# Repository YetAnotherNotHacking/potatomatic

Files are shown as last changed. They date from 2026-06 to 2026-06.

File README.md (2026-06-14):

<p align="center">
  potatomatic-cover
</p>

# Potatomatic turret system
Potatomatic started as a project to move a 5.5lb potato cannon reliably on a robotic turret mechanism, and to have intelligent tracking allowing it to automatically control itself for a majority of it's operation. We then realized that its super simple to make it adaptable to anything! So in the end, this project is a robust 2 axis gimbal with a mounting solution allowing anything to be mounted easily for use in the future.

## Assembly guide
A complete guide to printing, assembly, wiring and programming can be found [here](https://docs.google.com/presentation/d/1axM6zSbhQgakMfhfwyYygMVe3PKqu1EDHwFVl_Ch5AA/edit?usp=sharing).

## Bom:
See the BOM.csv for the BOM. It includes everything you would need to build it assuming you had only filament. See the google doc below for what the HackClub funding would be spent on, as thats the materials I still need.

**If you dont have anything, use the BOM.csv**

**I will be purchasing from the google doc BOM, as it omits things I already have**

All of the sourcing and stuff was done on this google doc:
[Google Doc BOM](https://docs.google.com/document/d/13_K_9BwoxUnn-ND7bYpN881mAYJAPF880q18yzIybXw/edit?usp=sharing)
See the "sourcing" tab for the real BOM. The first page is a general list without prices or source locations. Note that prices are calculated for Utah.

## Project Cost Breakdown
**For HackClub reviewer: I will NOT be purchasing filament with the project grant. I have already printed all of the components out with my own funds using my PETG.**

### Summary

| Category | With Filament | Without Filament |
|---|---|---|
| Total (inlc-tax) | $158.38 | $116.54 |
| Amazon Section | $123.16 (~$132.34 w/ tax) | $84.22 (~$90.50 w/ tax) |
| Bolt Depot Section | $26.04 | $26.04 |

---

## Amazon Parts

| Item | Cost |
|---|---|
| Filament | $38.94 |
| Controller (Arduino + stepper driver combo) | $17.83 |
| Stepper output flanges | $6.99 |
| DC-DC Step Down (24V → 12V) | $9.99 |
| Barrel Power Connector | $3.97 |
| Motor Cabling | $7.89 |
| C13 Socket | $5.99 |
| Thrust Bearings (2× 15×28×2mm) | $12.38 |
| Thrust Bearing (1× 80×105×4mm) | $9.19 |
| M3 Screw Set | $9.99 |

---

## Bolt Depot Parts

| Item | Cost |
|---|---|
| 4× 1.5" 7/16 Bolts | $2.72 |
| 9× 1.25" 7/16 Bolts | $5.31 |
| 13× 7/16 Nuts | $4.94 |

## 3D model
{4FDD96C2-EDEC-4343-98A4-A21E9CE5DD90}

## Wiring
Below is very professional Google Slides diagram of the wiring. I omitted the pi to better fit on one slide, since its only USB connectors that can go in one place one way. Note my typo, apparently cat5a doesnt exist. I meant cat5e. I got mixed up with cat6a which I use for my homelab.

wiring

The pi will have a webcam conencted, and serial connected to the control board. The wiring for this project is very simple, there is a limited number of electrical components other than the motors and camera and control boards. The control board does almost everything, if you look at what I linked its a steal honestly.

## Other notes:
The plan is to have entirely custom firmware for the turret, it will use a pi 5 that I already have as well as a camera attached to the turret (will have to be built before I can get a good idea of the best place) for targetting automatically. The main control will use the linked arduino stepper controller board with the pi talking to it with serial commands. There is a later intention of mounting it ontop of my friends car for some funny turret activities (dont ask) as well as adapting it for directional antennas to do radio astronomy, connecting to gpredict.

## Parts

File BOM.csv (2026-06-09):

name | number | link | cost | total
Controller, Arduino, Stepper Driver combo | 1 | https://www.amazon.com/Printer-Engraving-Expansion-Controller-Arduino/dp/B074DVRZDL/137-9649963-2915629 | 17.83 | 17.83
Stepper output flanges | 1 | https://www.amazon.com/ZXHAO-Flange-Coupling-Motors-Bearing/dp/B07HK8LQWC/ | 6.99 | 6.99
DCDC Stepdown 24v-12v | 1 | https://www.amazon.com/EPBOWPT-Converter-Regulator-Voltage-Transformer/dp/B07V6X6L89 | 9.99 | 9.99
Barrel power connector | 1 | https://www.amazon.com/California-JOS-Male-Female-2-1x5-5mm/dp/B0CR8TZ41W | 3.97 | 3.97
JST-XH terminated cabling | 1 | https://www.amazon.com/ACEIRMC-10Pairs-Connector-Connectors-Compatible/dp/B0D3LV6X3Y | 7.89 | 7.89
C13 Male Connectors | 1 | https://www.amazon.com/Panel-Adapter-Connector-Socket-MXR/dp/B07DCXKNXQ | 5.99 | 5.99
Thrust Bearings 15x28x2mm | 2 | https://www.amazon.com/uxcell-AXK5578-Bearings-Diameter-Thickness/dp/B07GC9J18L?xpid=99cDBU9-PCR3I | 6.19 | 12.38
Thrust Bearings 80x105x4mm | 1 | https://www.amazon.com/uxcell-AXK5578-Bearings-Diameter-Thickness/dp/B07GC94P6Y?xpid=99cDBU9-PCR3I | 9.99 | 9.99
M3 Fastener set | 1 | https://www.amazon.com/Fgruh-750PCS-Assortment-Washers-Assorted/dp/B0FGV5FCBN?th=1 | 9.99 | 9.99
7/16-14 1 1/2" Bolts | 4 | https://boltdepot.com/Product-Details?product=377 | 0.68 | 2.72
7/16-14 1 1/4" Bolts | 9 | https://boltdepot.com/Product-Details?product=376 | 0.59 | 5.31
7/16-14 Nuts | 13 | https://boltdepot.com/Product-Details?product=5574 | 0.38 | 4.94
CR20 Pro power supply | 1 | https://store.creality.com/products/creality-350w-power-supply | 22.81 | 22.81
Creality 42-40 Nema 17 Stepper | 1 | https://www.creality3dofficial.com/en/products/2pcs-ce-certification-2phase-reprap-stepper-motor-42-motor-42-40-3d-printer | 10.495 | 10.495
Creality 42-34 Nema 17 Stepper | 2 | https://www.creality3dofficial.com/en/products/2pcs-ce-certification-2phase-reprap-stepper-motor-42-motor-42-40-3d-printer | 10.495 | 20.99
Cat5 Ethernet cable | 1 | https://www.amazon.com/Monoprice-Flexboot-Cat5e-Ethernet-Patch/dp/B00KXM1LZ8?s=pc&th=1 | 2.42 | 2.42
6mm gt2 timing belt | 1 | https://www.amazon.com/Timing-Meters-Creality-Anycubic-Printer/dp/B097T3Y6WW?s=industrial&th=1 | 9.99 | 9.99
Power cabling | 1 | https://www.amazon.com/Voltage-Automotive-Primary-Security-Electrical/dp/B0CZ73SQP8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 | 8.99 | 8.99

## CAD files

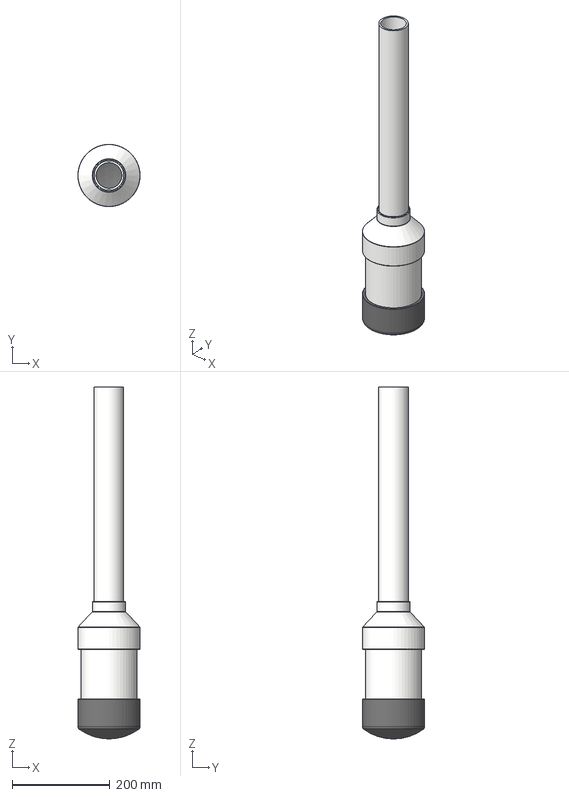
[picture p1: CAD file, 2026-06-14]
cad/cannon/cannonassemblyv2.step
127.0 x 127.0 x 719.2 mm

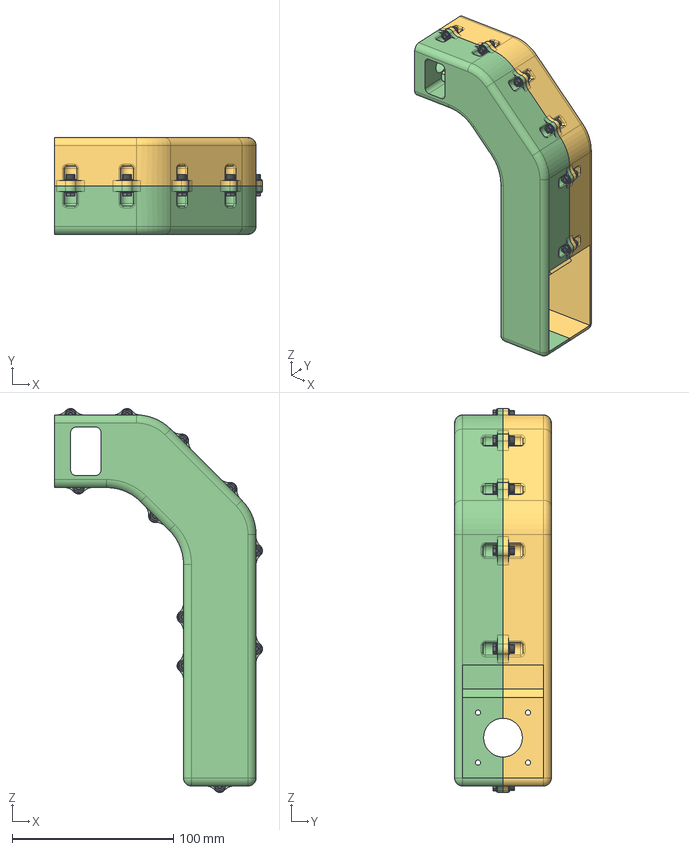
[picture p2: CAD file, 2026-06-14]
cad/assemblies/assem_manu1_armelementv1.step
129.0 x 60.0 x 238.0 mm

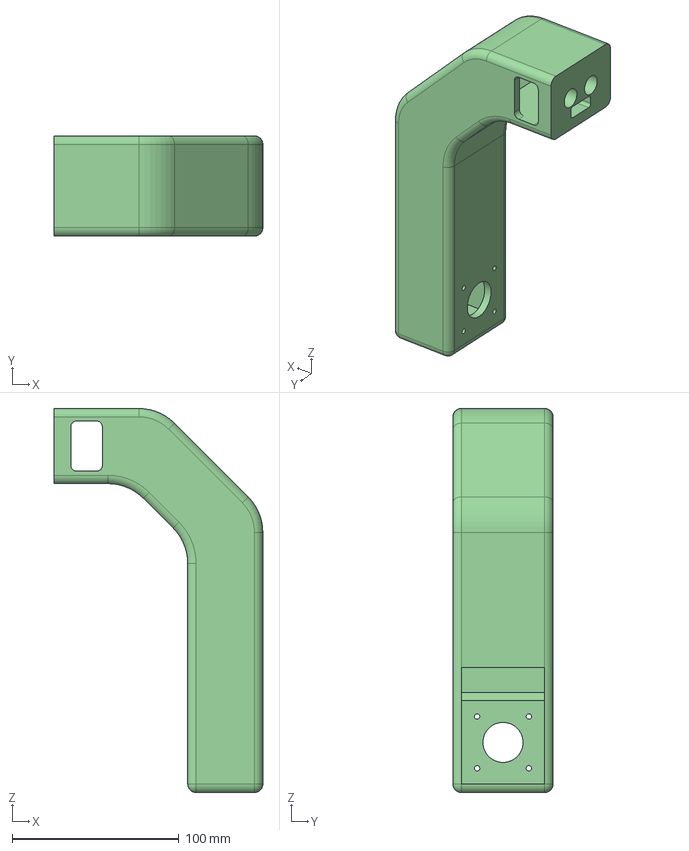
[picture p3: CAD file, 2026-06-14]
cad/geometry/armelementv1.step
125.0 x 60.0 x 230.0 mm

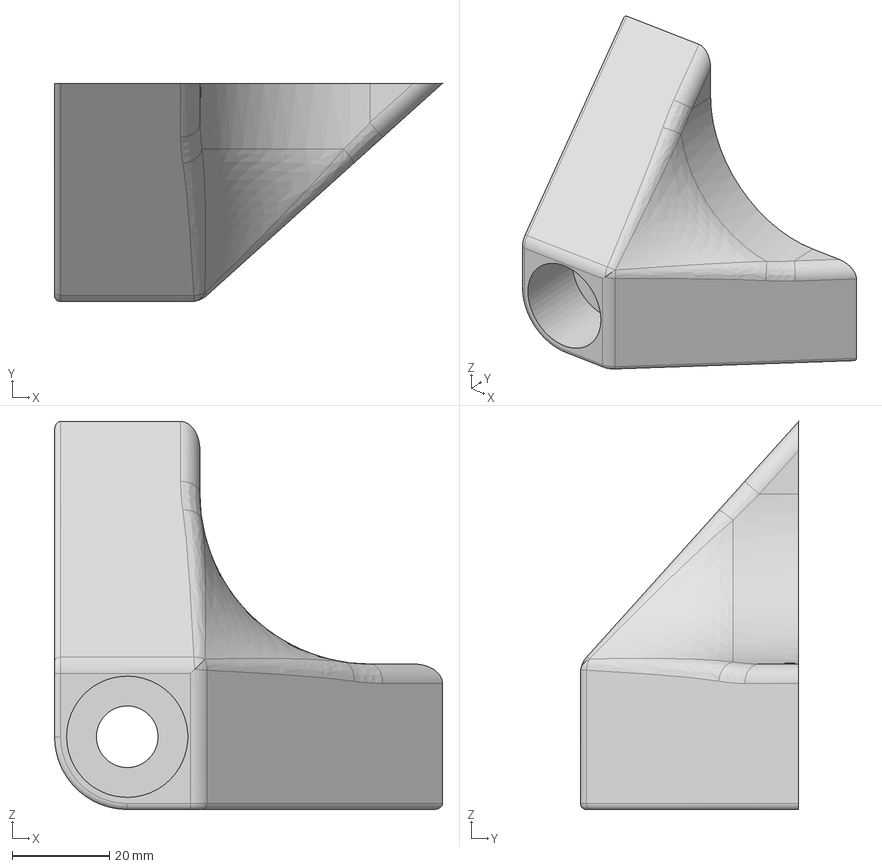
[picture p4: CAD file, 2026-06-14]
cad/manufacturable/basefootv1.step
80.0 x 45.0 x 80.0 mm

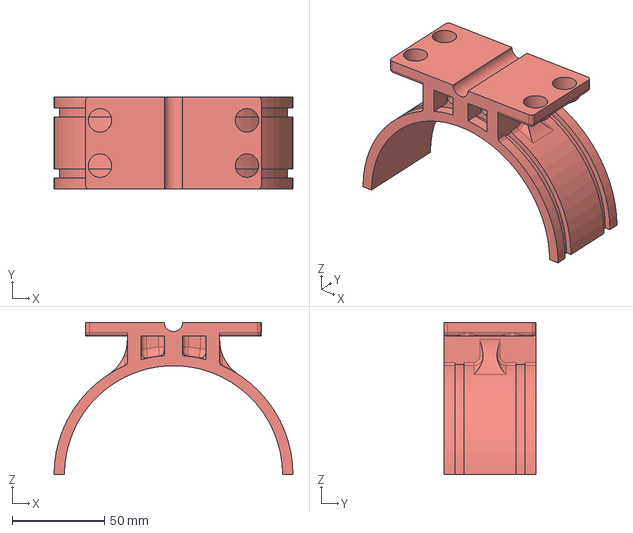
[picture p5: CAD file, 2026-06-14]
cad/payload_adapters/cradle_cannon.step
129.3 x 50.0 x 82.5 mm

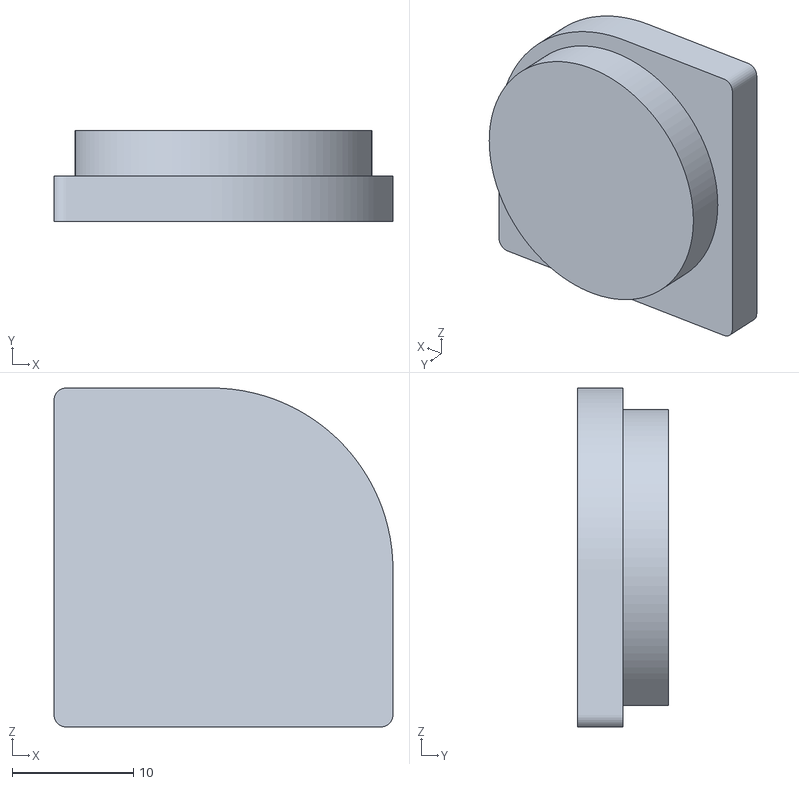
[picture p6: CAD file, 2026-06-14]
manufacturables/footcapv1.stl
28.0 x 7.50 x 28.0

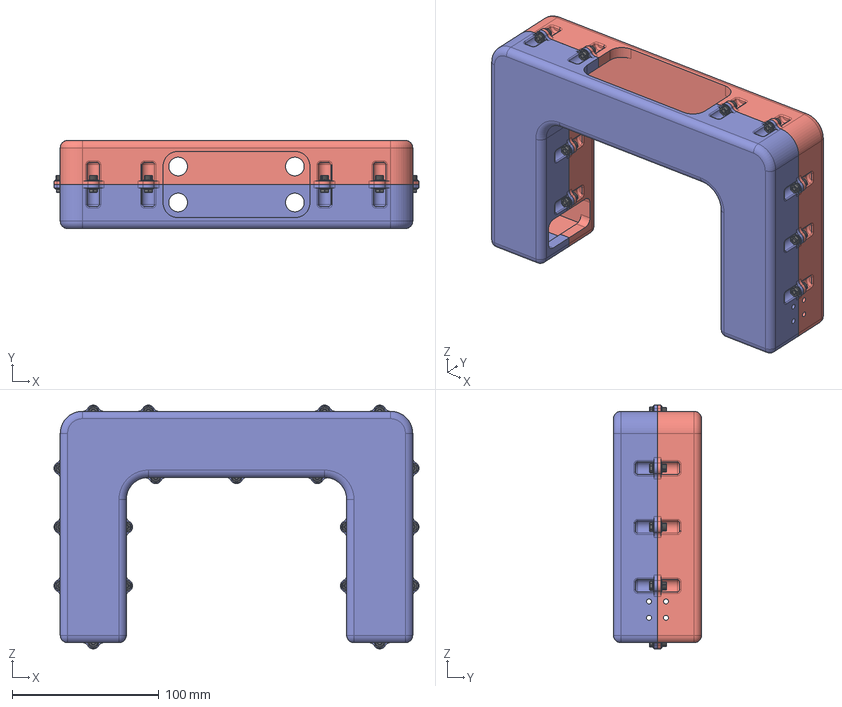
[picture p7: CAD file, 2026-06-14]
cad/assemblies/assem_wristelement2.step
248.5 x 60.0 x 166.0 mm

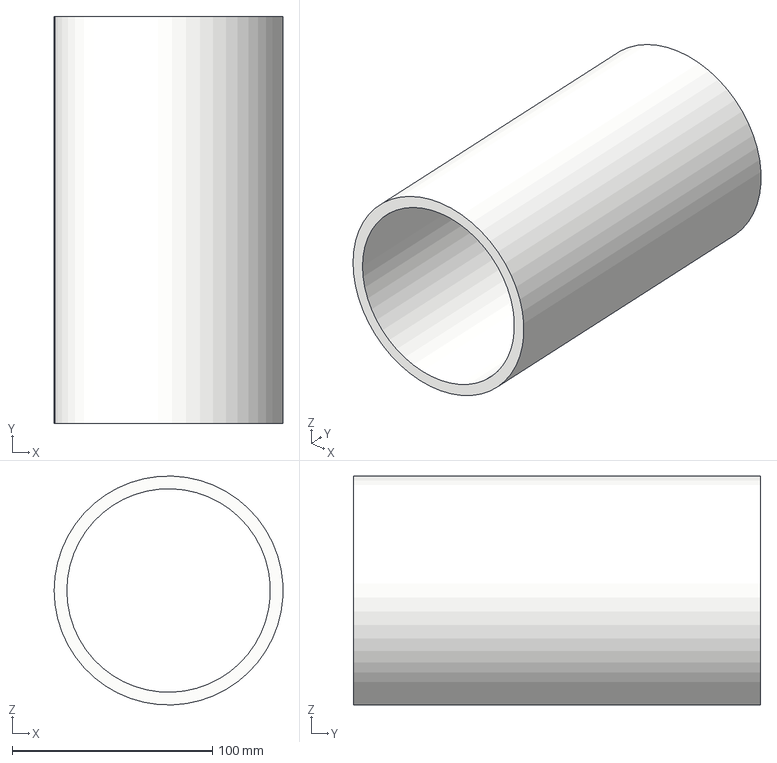
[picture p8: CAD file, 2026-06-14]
cad/cannon/4inpvc.step
114.2 x 203.2 x 114.2 mm

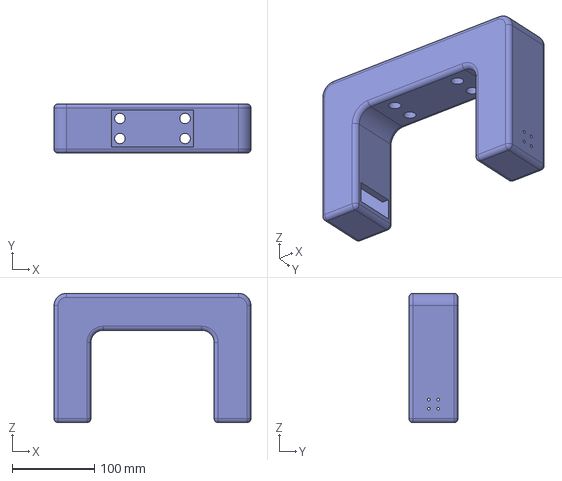
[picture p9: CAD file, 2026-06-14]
cad/geometry/wristelement2.step
240.0 x 60.0 x 157.5 mm

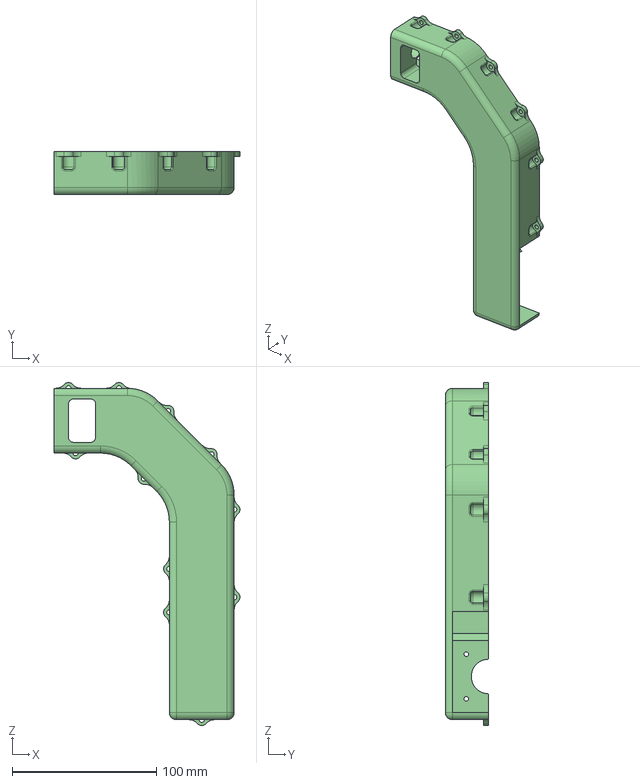
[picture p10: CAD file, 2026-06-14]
cad/manufacturable/a_manu1_armelementv1.step
129.0 x 30.0 x 238.0 mm

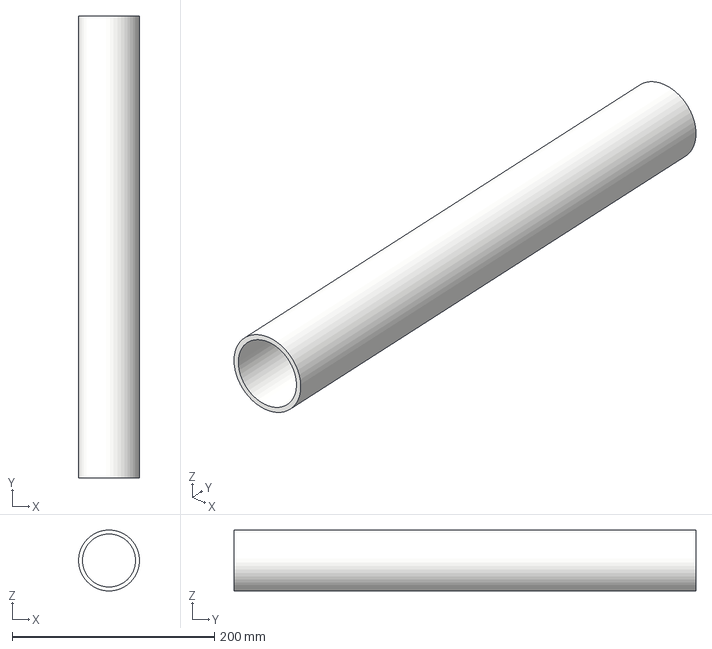
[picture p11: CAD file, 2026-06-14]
cad/cannon/2inpvc.step
60.3 x 457.2 x 60.3 mm

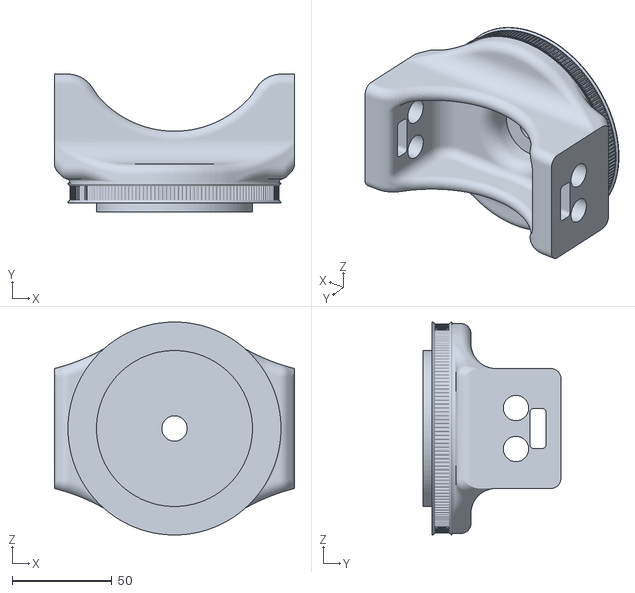
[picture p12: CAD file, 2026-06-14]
manufacturables/jointbase.stl
120.0 x 69.0 x 106.5

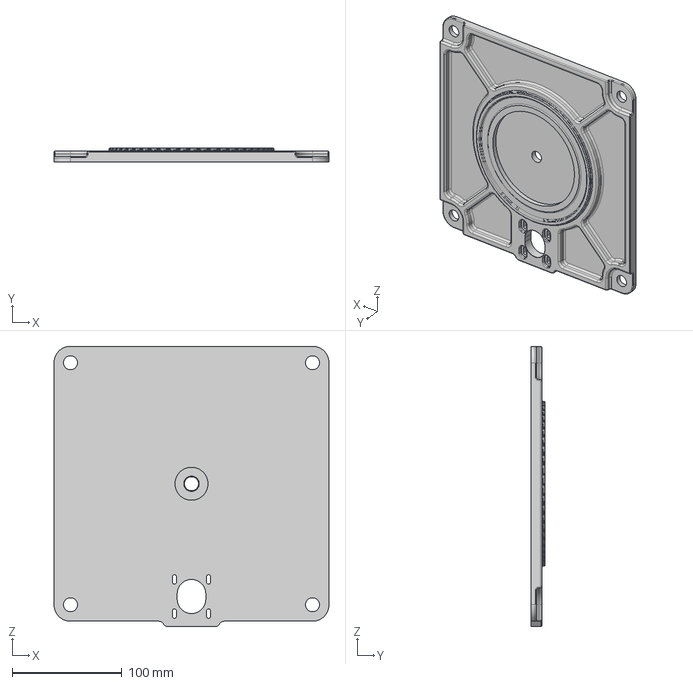
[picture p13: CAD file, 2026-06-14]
cad/manufacturable/base.step
250.0 x 13.0 x 255.0 mm

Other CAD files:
manufacturables/elementa_manufacturing_armelement.stl
cad/manufacturable/b_manu1_armelementv1.step
manufacturables/base_manufacturable.stl
cad/manufacturable/footcap_footv1.step
manufacturables/cannon-mount.stl
cad/manufacturable/jointbasev1.step
cad/manufacturable/manu1_wristelement2.step
cad/manufacturable/manu2_wristelement2.step
manufacturables/elementa_ushape.stl
manufacturables/elementb_manufacturing_armelement.stl
manufacturables/elementb_ushape.stl
manufacturables/footv1.stl

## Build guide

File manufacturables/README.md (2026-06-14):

\# Manufacturables

This is a collection of all of the parts that you are going to need to be able to make the project. I will breakdown here how many of each part you are going to require.

For all parts, use PETG filament with tree supports.

\## elementa\_ushape

This is the first half of the ushape that the payload attachs to, you need one.

\## elementb\_ushape

This is the second half of the ushape that the payload attachs to, you need one.

\## base\_manufacturable

This is the main base peice for the project, make sure you have supports for the weird bearing hole in the middle, you need one

\## elementa\_manufacturing\_armelement

This is one half of one of the arms, use tree supports for everything (not "only touching buildplate!!!). You need two of this.

\## elementb\_manufacturing\_armelement

This is the other half of one of the arms, use tree supports for everything (not "only touching buildplate!!!). You also will need two of this.

\# footv1

This is the foot for the base, one of the many mounting options. you need 4 of these and no supports. print on top face.

\# foot cap v1

These are bolt hole covers for the feet for more surface area on the ground, you also need 4 of these.

\# cannon-mount

this is the mount for the cannon payload. its a very complex print, you may want to find a good printer to print it on. Use tree supports not only on buildplate, slower printing speed with partend fan always at 100% (set it in your slicer). you only need one of these.

\# jointbase

this is another complex one, use tree supports also NOT only on buildplate, ensure the pulley is well supported on all faces that are overhang, and you only need one of these.

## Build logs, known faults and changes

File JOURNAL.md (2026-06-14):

# June 4: Working on the cad.
I spent a lot of time today getting the geometry of the gimbal put together. I knew that I would need some sort of thrust bearing, and a way of putting all of the load of the turret assmebly onto that bearing. I ended up using a strategy of sandwhiching the bearings together.
This sandwhiching meant that no matter how load was applied to the bearing, it would always go into the main thrust bearing instead of anything else, which would make a very rigid and reliable pan joint.



You can see in the image here, its simply a thrust bearing with a screw in the middle on the base. This will make more sense when the rest is more built.



The load here is entirely on that thrust bearing, with two thrust bearings on either side of the bolt holting it in to ensure that it continous to rotate fully freely regardless of what direction or kind of load is put on the platform.



Here I am brainstorming ideas on how I could build that arms that go up. I end up realizing this wide sqaure collides with the drive motor for the pan that isnt modeled in right now.



I brought in my cad of the turret, with some basic offset extruded cubes and lofts to represent how the wrist element will look in the design. It should be noted that this is not how the cannon is going to look, this is 6 in to 4 in pvc, when the cannon is 4 in to 2 in. Also, it is going to be design for things other than just a cannon.



This is an early draft of the new version I am going to be actually implementing. You can see there is one base element with the drive pulley that everything is sitting on. It then attaches to two detachable arm elements that are going to hold up the steppers and the rest of the turret.



Here is a section analysis I sent to a friend explaining my design of the bearing, You can see the larger bearing that all of the load is being placed on, as well as the bolt going through it with the two other smaller thrust bearings keeping the rigidity of that joint well.



Here you can see roughly where I ended. I did end up putting some flanges on the shafts of the motors that will be actuaing the tilt of the cannon/payload in the future. The load will be directly applied to the output shafts of the motors, however, its less load esimated then what I saw in the 3d printer that they were taken from.

I spent all day from ~1 pm to about ~2 am working on this project, im omitting roughly the amount of time where I wasnt actively doing cad/only staring at the screen figuring out how to do something.

Future edit: I realize I underdocumented this time. To back up these times, here is the fusion save logs for the files I was working on. Lapse wasnt working for me on brave or firefox when I did this, so no lapse sadly. I cante tell whats happening with the time zone, I closed my laptop a little before 2 if I remember right.

Master assembly logs:

{49FA15DD-B45C-48A6-B1F6-3984A9533B8C}

Base (the big platform) logs:

{0E2341AA-A63B-40C0-A156-0819D153B60E}

Search history of thrust bearings:

{82E3026B-17E8-4CB0-BB31-0B88B1DBE8B6}

THe little bit I was scrolling to see if anyone had a similar design

{0828613C-51AA-43DF-A46E-E4A18FE4D5B8}

Everything seems ahead by like 2 or 3 hours, cant tell you why honestly. My browser is usually wrong, but my laptop with fusion has the correct tiem right now. I grabbed most of these screenshots/phone pictures of the cad from Discord that I sent to my friend when I realized I did all of that work without journaling. LMK on slack if you are reviewing this time and are still skeptical, I can provide any logs or whatever you need.

** Total time spent: 8.6 hours **

# June 5: Lock in session with friend, doing second stage of the turret and an adapter to hold the potato cannon
Today is the day I actually remembered that I need to jounrnal. Yesterday's journals were written today, with the images I sent to my friend on Discord. That friend was over today, and kept me motivated and helped me fix the design for the rest of geometry mockup of the project. **I am only logging the time I put in today before he arrived, or what I put in while he was here. His worked is NOT logged as mine**

{12CD24D2-11A8-425E-81FC-AC176E9FD33C}
{08C7C380-E61E-42E8-B887-73224CB8F9A9}

This is the final cad that we arrived on today. You can see that there is a generic payload mount, and there is a rough model of what a zip tie based attachment for a potato cannon might look like. The zip ties is to make it easy to remove the potato cannon for further improvements (possibly replacing the hair spray based system with pneumatics) as well as being able to use the cannon alone.

Soon after finishing this design. I pitched it to my father for possbile further support in funding, however, he disliked the cannon idea due to the danger, so this project will not be used for a potato cannon anymore. The design of an easily adaptable payload will prove helpful.

Time was also spent today figuring out how a pneumatic firing would work, we spent a couple hours searching existing designs and realiaed the only way we could achieve such a design was with a solenoid value. They only make solenoid valves for small (small, 1/2 inch) pipes unlike our 2 inch firing pipe. We expiremented with having a segment of 1 inch pipe that we could adapt to the solenoid valve, but we realized it would restrict the flow too much and is simply too complicated to work reliably. We also would need to store air in the larger compartment and we were very woried about that assembly exploding with the pressure required to launch the potato.

We also spent about an hour sourcing all of the parts needed to put together this project, going to all of the cheapest places that we could think of. We planned to go to home depot for the cannon materials before that was scrapped, so we were able to remove the arc generator and pvc material that were listed. This took about 40 usd of our total. All other materials were still required. All of the electrics, pulleys and flanges that were in the model are sourced cheapely from amazon, and the 7/16ths bolts for the lengths and ammounts we needed were actually cheapest from McMaster, which is a rare occurance. Overal the parts list without the canon amounts to about 162 dollars. We will need to work more for this funding.

The design is taking advantage of several components that are already available from a decomissioned cr20 pro we got from a friend. The steppers, power supply, raspberry pi, are available. I also have some 6mm gt2 timing belt from another project that we can use for the pan axis, as the model in cad uses it for a lowered ratio and easier actuation.

BOM:
https://docs.google.com/document/d/13_K_9BwoxUnn-ND7bYpN881mAYJAPF880q18yzIybXw/edit?usp=sharing

The filament on there is an estimate for the iterations needed to get thsi project to move reliably. Its quite large, about 250x250 mm for the base and it will be taking full advantage of that size to adapt to larger payloads in the future (e.g. yagi antennas or something idk).

I need to fix several of the models (like the arms and the wrist part) to be more easily printed, as right now they are all hollow and impractical to put supports inside of, so I will split them apart and fasten them together in some method, likely m3 screws since they are already on the parts list and are easily available.

** Total Time Spent: 5.6 hours ""

# June 6: Manufacturability
I am spending today making sure that all of the parts in the design are easily printable with the materials that I have.

{84A86445-6A24-493F-8E4F-33F0F91A468B}

Above you are able to see the work done for the center element of the turret. I split it into two halves and added several (several for the rigidity) m3 screw points to fix the two halves together.

{E2C26ED9-06B3-45D8-9B5E-A8A21FC8A49A}

The intention is to print it in this orientation, with tree supports going up to support the screw holes. This fixes the problem before where there was large cavities in these parts that were impossible to print because you cant remove supports from them, and not having supports just wouldn't work on me or my friend's printers. (mine is snapmaker a350, his ender 3 v2, both meh printers compared to a bambu)

I am going to continue working on this, adding screws to the appropriate lengths, verifying tolerances, and then doing the same for the arm assemblies. Hopefully I can keep those identical so the files stay the same, other than a left and right version of them for printing.

{8547E2E8-D016-4EF7-9B4E-318C335343D5}

Now all the screws are put in place. Above is what it looks like now.

{DCD7BBF9-5F9B-41F5-918E-DBF829EBC35A}
{74F02BAC-A1C1-4202-B171-741E0885B517}
{20C95B25-2388-4199-91FA-5655854A429B}

Above is the new arm design, there are two seperate models since this one could not simply be flipped around like the other one, it had to be actually mirrored since its not symetric on that axis. I will now assembly it back into the main design, almost all of the joins are broken so I will delete and redo the top half of the turret in the main assembly for that.

{72665906-90F0-47E8-8DB7-2520E02BC878}
{D8DE048A-3025-4200-A3A4-52B7ED1DF960}

Above you are able to see what the new full assembly is looking like.

{B28E8F57-4B07-4C34-807B-87B31B2321DB}
{05549D3E-0A6F-4EC1-B0DC-5525B9C09E4B}

I fixed the fillets on the screw holes for both of the models.

{ACE0F1C9-FE56-4CE5-AC6E-F00398BDCB2A}

The smaller inside u was limited to being only 4 mm, thats because of the face you see above. The arms are 7.5mm radius on the fillets, but the ones for the center u are only 4.

{D2906C6E-7620-4179-91A3-5773D95EE3D0}
{856D74C0-98F6-4C01-9C2F-BFD9C98CC4D5}
{DFD8472D-B1A9-49D4-8ADF-0C27886A4A51}

I realized that the motor sticking out was sort of optional, so I decided in favor of using a little less filament to move it in like you see here.

{35516E54-B6FD-4C0E-BD6D-D6E2F74AFDF5}

I had to increase the height of the feet for the motor to not be clipping into the ground. This is because the motor was lowered to the height of the bottom of the platform, both to make printing a little easier but also do make the shaft not clip into the arm while it rotated.

{9C6506C7-CD5B-4DB5-82B6-6C8F6E4AE5F0}

Here is what the updated model is looking like with the potato cannon payload. I think that I will next work on covers for the side motor arm things.

I updated the BOM and found cheaper sourcing then McMasterCarr for the bolts (being Bolt Depot, they look pretty trustworthy and the entire cost WITH SHIPPING is less than the cart on mcmaster without.)

Again, here is that BOM:

https://docs.google.com/document/d/13_K_9BwoxUnn-ND7bYpN881mAYJAPF880q18yzIybXw/edit?usp=sharing

I will continue to reduce the amazon cost what I can, but I will need about 5.1 more hours to get the funding required to build this project.

{6D8C674E-2109-44D0-B431-AE065116E4EB}

{46A1C294-DED1-4B96-8726-D10BE9B9392B}

As you can see, my amazon is tweaking. I am still trying to optimize the parts list a little more. I noticed that the thrust bearings were entered wrong, and I am going to have to change them. I also noticed I still had the unused limit switches listed, so I will be removing those as I found the ones that were part of the cr20 and I will plan to use those instead.

I got amazon to work on my thinkpad, idk why my framework wouldnt load the product information. Anyway, I removed the limit switches, removed the drive pulley since I found one with the belt that would work, and fixed the bearings. I will now recalculate the totals.

The other two things that I thought I would be able to cut some cost with were the c13 power connectors and the output flanges for the stepper motors. The flanges were 2x6.99, but I found the same thing but a two pack for 1x 6.99 (I didnt look very hard initially, that came back to bite me of course). The footprint appears super similar, so I wont have to modify the design from my understanding. I will now resum, hopefully we are less overbudget :pray:
It looks to be about a 13 dollar reduction in cost! I will recalculate the tax and see how far over we still are.

{52462BDD-EF0E-4F46-B97A-9C71E3CCECD3}

These are the new totals! (Including tax!!) This is much better than the previous.

For the past bit I have been working on the renders of the design and figuring out any improvements i can make with the extra time. I have been measuing our design, and it would not be that difficult to go pneumatic. A friend told me about their potato cannon when I sent them the render for feedback, and they are using a tire bead setter adapted to shoot the potatos.

Something like this one:

https://www.amazon.com/Handheld-Portable-Inflator-87-116PSI-Operating/dp/B0F8HGR4GK?psc=1

I have mainly spent this last bit of time rendering and figuring out a v2 in the future.

{FA256CC0-AC7A-445A-9292-F7148306CE44}

For the tire cannon to fit,  we would need to cut about this much out of the secondary element of the shooter. This might be too much, especially because the air cannon would have a ton of kickback

{FAE74DED-575E-4340-B2EE-0EABCBE996A7}

{FAE74DED-575E-4340-B2EE-0EABCBE996A7}

I found some stuff I forgot to fillet on the base, so I fixed that.

{87C08A37-DA23-48ED-8628-2EE8EDFDDD7E}

I also added in the screws for the upper motors on the thing.

{87A86590-1B36-4AEA-9726-24EF89E67897}

I added a janky fix to the old potato cannon payload adapter to fit over this screw.

{0F7E2F91-2DB1-4600-8CA7-B893A32EEE5B}

I added these foot covers to increase the surface contact the feet have. I might make this texturing in the future for better grip, but for now I will just plan to put cat tongue tape onto it.

For context, this is what it looked like before:

{A0DBF313-4105-41BB-80D6-286B5AE7AF1B}

** Total time spent: 7.0 hours **

# June 7: Shipping
Today I did as much as I could to make sure that the project is ready to ship. I created some basic code to run on the arduino in the cnc sheild, as well as a web gui for control for my rpi I will connect to the sheild. I dont have any of the materials to be able to test this code, but I will assume it works. ChatGPT says it looks good so it DEFINTELY will work. I got the pinouts from ChatGPT, luckily it knew the board and was able to find the pinouts in the grbl wiki for the CNC Sheild v4 to drive the steppers.

This code is very simple for the arudio, you can see it below:

{6C9B7BE2-F8D2-4B2B-A326-7776407CC1D8}

The plan is to send the commands to the arduino over serial, in the following form: 

0 400\n

Thos would move motor 0 (the python code is assuming this will be the turn motor) right 400 steps from my understanding of how this board works. Its just sending step commands, I really need to expirement with this hardware in person to figure out how to do anything more advanced.

{6FDD3234-3B3D-4847-9E40-B570ED224381}

This is the very simple web gui, this is mainly just to help me figure out the motors wiring and how they move and respond to the commands, you can see that the two turning motors are seperate (which would not end very well). This is only to test, and it will be fixed when it is some to actually assemble the project. This does ignore the x y and z on the controller board, they will all be used not in that way. Its just sending step commands to the pins on the pcb from my understanding of the way the pcb works from ChatGPT.

Other than the code, I formatted the readme, made the table for the BOM by giving ChatGPT my original one, linked the main BOM, and some other final tweaks for the project.

** Total time spent: 1.6 hours **

# June 8: Polishing the ship while I wait for review

I already wrote this journal but it looks like I never press commit :sad:

Anyway, today I spent a good deal of time making this ship look a bit better, finalized the BOM with parts not assuming the stuff I already had, made a real wiring diagram, and some other things. I wont go into much detail, this stuff really didnt take that long so ill just show what I did.




** Total time spent: 0.4 hours **

# June 9: Fix minor model issues

We realized that there was no method in the model of being able to tention the main belt for the pan axis. We changed the model to use slots rather than holes for mounting that motor with 5mm of movement to allow proper tentioning once the model is built.

{DE3CC4B5-9CE0-44D4-93F7-275BC98AD09F}

Another thing we fixed was the pulley being seperate in the turret base model

{19069945-130D-413F-8599-325747CD0E2C}

Before they were seperate bodies that would not export and print correctly, but my friend reminded me that the combine tool exists, and we were able to get that fixed. I will lend him filament and he will lend me some machine time on his printer.
The 
I have also been running the printer for some of the parts. Below are images of what they are turning out like.





** Total time spent: 0.5 hours **

# June 14: Assmebly guide, exporting cad, fixing return reasons

I got returned for the following reason:

{4D03D1D8-CFE8-400F-AE08-8D4B1913FE48}

I broke that down into things that I am able to solve today:

 - Cad files in step format
   - Separate folder
   - Assembled
   - Individual files
 - Assembly instructions with images
 - Clarify I wont be buying filament with grant
 - Singular BOM with links and prices
   - Clarify bom with what I have vs everything you need.

THe CAD files are now all available here: [link](https://github.com/YetAnotherNotHacking/potatomatic/tree/main/cad)
Assembly instructions are available here: [link](https://docs.google.com/presentation/d/1axM6zSbhQgakMfhfwyYygMVe3PKqu1EDHwFVl_Ch5AA/edit?usp=sharing)

The clarifications on funding have already been applied to the readme.

The assembly guide took about 1.5 hours, collecting all of the slice screenshots, cad screenshots, organizing everything, hiding parts of the model and writing all of the explanations was quite time consuming. I also spent about 30 minutes exporting everything from fusion and trying to organize it a little bit, as well as writing a couple of notes about what the parts were and how many were needed that are also in the assembly guide. I also collected links to put them into the assembly guide. I had to find some way to explain the belt, I dont have anything so I found a youtube video that explains it pretty well and in a short form factor. Just note that isnt my media.

** Total time spent: 2.0 hours **

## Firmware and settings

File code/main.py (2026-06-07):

# Quick scrappy python controller for the potatomatic project, just a simple web gui talking to the arduino. I will expand on this once the rest of the project has been constructed.
from flask import Flask, request, redirect
import serial
import time

app = Flask(__name__)

# connecting to the arduino
SERIAL_PORT = "/dev/ttyUSB0"
BAUD = 115200
ser = serial.Serial(SERIAL_PORT, BAUD, timeout=1)
time.sleep(2) # wait for finalization

state = {
    "speed": 800, # base speed for movement
    "turn_ratio": 165/16 # ratio of pan drive pulley to the moving pulley.
}

# send a motor command to the arduino controller
def send(motor, steps):
    cmd = f"{motor} {int(steps)}\n"
    ser.write(cmd.encode())

# turn with ratio
def scaled_turn(steps):
    return steps * state["turn_ratio"]

# serve the scrappy web pannel to control it
@app.route("/", methods=["GET"])
def index():
    return f"""
    <h1>turret controller</h1>

    <form action="/move" method="post">
        <input name="steps" value="100">
        <input name="speed" value="{state['speed']}">
        <button name="action" value="turn_left">Turn Left</button>
        <button name="action" value="turn_right">Turn Right</button>
        <button name="action" value="tilt_up">Tilt Up</button>
        <button name="action" value="tilt_down">Tilt Down</button>
        <button name="action" value="tilt2_up">Tilt2 Up</button>
        <button name="action" value="tilt2_down">Tilt2 Down</button>
    </form>

    <form action="/speed" method="post">
        <input name="speed" placeholder="speed">
        <button>Set Speed</button>
    </form>
    """
# set speed from update
@app.route("/speed", methods=["POST"])
def speed():
    state["speed"] = int(request.form["speed"])
    return redirect("/")
# handle a move
@app.route("/move", methods=["POST"])
def move():
    steps = int(request.form["steps"])
    action = request.form["action"]

    if action == "turn_left":
        send(0, -scaled_turn(steps))

    elif action == "turn_right":
        send(0, scaled_turn(steps))

    elif action == "tilt_up":
        send(1, steps)

    elif action == "tilt_down":
        send(1, -steps)

    elif action == "tilt2_up":
        send(2, -steps)   # inverted, ones mirror

    elif action == "tilt2_down":
        send(2, steps)    # inverted, ones mirror

    return redirect("/")

if __name__ == "__main__":
    app.run(host="0.0.0.0", port=5000)

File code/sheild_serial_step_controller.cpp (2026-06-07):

const int stepPins[3] = {2, 3, 4};
const int dirPins[3]  = {5, 6, 7};
const int enPin = 8;

void stepMotor(int m, long steps) {
  if (steps == 0) return;

  digitalWrite(enPin, LOW);
  digitalWrite(dirPins[m], steps > 0);

  long s = labs(steps);
  for (long i = 0; i < s; i++) {
    digitalWrite(stepPins[m], HIGH);
    delayMicroseconds(800);
    digitalWrite(stepPins[m], LOW);
    delayMicroseconds(800);
  }
}

String line;

void setup() {
  Serial.begin(115200);
  for (int i = 0; i < 3; i++) {
    pinMode(stepPins[i], OUTPUT);
    pinMode(dirPins[i], OUTPUT);
  }
  pinMode(enPin, OUTPUT);
  digitalWrite(enPin, LOW);
}

void loop() {
  while (Serial.available()) {
    char c = Serial.read();
    if (c == '\n') {
      int m;
      long steps;
      sscanf(line.c_str(), "%d %ld", &m, &steps);
      if (m >= 0 && m < 3) stepMotor(m, steps);
      line = "";
    } else {
      line += c;
    }
  }
}

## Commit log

2026-06-07 update screw image
2026-06-07 update information on the new arm design with the split design for printablilty
2026-06-07 update with full assembly image
2026-06-07 update information about motor and some other stuff
2026-06-07 update with new bom information
2026-06-07 update information about the BOM
2026-06-07 update BOM total with new amount and update time for time spent (rolling over into new day already)
2026-06-07 update with bolt cover for feet images and reasons
2026-06-07 fix bom link
2026-06-07 update bom again it will work this time bc chatgpt made the link :100:
2026-06-07 update with wiring information
2026-06-07 add an export of the cad
2026-06-07 add basic controller for the arduino (I dont know, I will need to test I have no idea honestly)
2026-06-07 basic web gui to control the turret arduino with a web gui
2026-06-07 Clarify the tax on the bom cost
2026-06-09 update with new wiring diagram
2026-06-09 update ethernet cable typo thing
2026-06-09 update to point to proper BOM
2026-06-14 add exports of the cad in step format for ship
    [2inpvc.step, 4inpvc.step, a_manu1_armelementv1.step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]
2026-06-14 clarification on filament use
2026-06-14 clarify BOM
2026-06-14 remove wrong file format for foot cap
    [footcapv1.step]
2026-06-14 update with assembly guide
